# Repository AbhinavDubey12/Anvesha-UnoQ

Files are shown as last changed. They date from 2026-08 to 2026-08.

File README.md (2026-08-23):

# Anvesha — Autonomous Vision & Gesture-Controlled Rover

Autonomous rover built on the Arduino UNO Q (dual Linux MPU + STM32 MCU), combining reactive ultrasonic navigation, live on-device hand-gesture recognition via camera, and IMU-based safety monitoring — with a motor-control layer executed by a dedicated ESP32.

## Overview

By default, the rover navigates autonomously using three ultrasonic sensors (front/left/right), avoiding obstacles reactively. A physical button toggles an additional camera mode: a live ESP32-CAM feed is processed on-device by a custom-trained Edge Impulse object detection model, recognizing hand gestures that trigger specific rover actions. An MPU9250 IMU runs continuously as an independent safety layer, watching for tip-over or sudden impact regardless of what else the rover is doing. A live relay lets the camera feed be viewed from any browser on the network at the same time.

## Features

- Default autonomous reactive navigation (3x ultrasonic, North/East/West)
- Button-toggled camera mode with on-device gesture recognition (Edge Impulse FOMO, INT8, running on the UNO Q's Linux side)
- Two recognized gestures: **FULL_HAND** (controlled reverse) and **THUMPS_UP** (choreographed movement sequence)
- Live, multi-client-viewable camera feed via a custom relay
- MPU9250-based tip-over/impact safety monitoring, independent of navigation or gesture state
- LED status indicators + buzzer feedback
- UART link between the UNO Q (decision-making) and a dedicated ESP32 (motor execution)
- Per-wheel quadrature encoders for distance tracking

## Hardware Components

| Component | Role |
|---|---|
| Arduino UNO Q | Main brain — Linux (camera/AI) + STM32 (sensors/decisions) |
| ESP32 Dev Kit V1 | Motor + encoder controller |
| ESP32-CAM (AI-Thinker) | Live video source |
| 4x DC gear motors w/ quadrature encoders | Drive |
| L298N motor driver(s) | Motor power/direction |
| 3x HC-SR04 / HC-SR04P ultrasonic sensors | Reactive navigation |
| MPU9250 | IMU — safety monitoring |
| 4x LED, 1x buzzer, 1x push button | Status/mode indication |
| Chassis, wheels, battery, wiring | — |

## System Architecture

```
ESP32-CAM (video)
      ↓
UNO Q — Linux side (Python): fetch frame → Edge Impulse inference → debounce
      ↓ (Bridge RPC)
UNO Q — STM32 side (sketch): ultrasonic + IMU + LEDs/buzzer/button → decision
      ↓ (UART)
ESP32: motor execution + quadrature encoder tracking
```

## Software Stack

- **Arduino App Lab** — dual-processor (Linux + STM32) app framework
- **Python** (Linux/MPU side): OpenCV, Edge Impulse Linux SDK, a custom lightweight MJPEG relay
- **C++/Arduino** (STM32 sketch side): `Arduino_RouterBridge` for Python↔sketch RPC, ultrasonic + IMU sensing
- **C++/Arduino** (ESP32 side): UART command parsing, motor control, interrupt-driven encoder tracking

## Wiring Overview

**UNO Q**
- Ultrasonic: D2–D7 (West/North/East, trig+echo pairs)
- MPU9250: D20 (SDA) / D21 (SCL) — I2C2
- UART to ESP32: D0 (RX) / D1 (TX)
- LEDs: D8–D11 · Button: D12 · Buzzer: D13

**ESP32**
- UART: GPIO25 (RX2) / GPIO26 (TX2)
- Motor direction (shared per side): Left IN1/IN2 → GPIO27/14, Right IN1/IN2 → GPIO13/15
- Independent PWM speed: FL=32, RL=33, FR=4, RR=23
- Encoders (A/B): FL=34/35, RL=19/21, FR=2/22, RR=5/18

Full reasoning behind each pin choice is in the code comments.

## Confusion Matrix 


## Key Engineering Challenges & Solutions

- **ESP32-CAM stream reliability:** `cv2.VideoCapture`'s FFmpeg/GStreamer backend proved unreliable against the board's minimal MJPEG server under real-world network jitter. Solved with a manual `urllib` + JPEG-marker-parsing fetcher, with reconnect-on-failure logic.
- **Single-client limitation of the ESP32-CAM's server:** its onboard server can only serve one viewer at a time. Solved by having the UNO Q relay already-fetched frames to any number of viewers via a lightweight custom HTTP MJPEG relay, rather than exposing the fragile camera directly.
- **Gesture model iteration:** started from a broader gesture set; iterative testing surfaced background-labeling issues, data-volume limits, and a genuine visual-similarity ceiling between finger-count gestures. Converged on two visually distinct, reliably-separable gestures for real-world performance.
- **App Lab dependency management:** `requirements.txt` must live inside the app's `python/` subfolder (not the app root), and requires a full app close/reopen — not just a re-run — for App Lab to pick it up.
- **Platform-specific I2C differences:** the UNO Q's STM32/Zephyr core uses a fixed-pin, no-argument `Wire.begin()`, unlike the flexible-pin-argument convention common in ESP32-based reference code.
- **Motor pin budget:** adopted a shared-direction / independent-PWM wiring scheme (paired left/right direction lines, 4 independent speed lines) to fit available GPIO while preserving per-wheel encoder telemetry.

## Known Issues

- **[N] of 4 drive motors are not reliably receiving power as of submission.** Root cause narrowed via isolated diagnostic testing to a likely power-brownout-under-load condition (motor and logic power sharing a supply), with a possible additional wiring fault isolated to specific motor channels. A fix (separating ESP32 logic power from motor power) was identified but not fully re-verified before the submission deadline.
- **Full closed-loop PID speed control was intentionally deferred**, given time constraints — a simpler proportional gyro-based heading correction and raw encoder-based distance tracking were implemented instead.
- **Speech recognition was scoped but intentionally dropped** to prioritize a fully working core pipeline within the available build time.

## Demo Video

(https://drive.google.com/file/d/1g66gReOm86e0tmXK2YHVcHV1n0MQbO11/view?usp=drivesdk)

## License

[MIT]

## Author

Abhinav Dubey

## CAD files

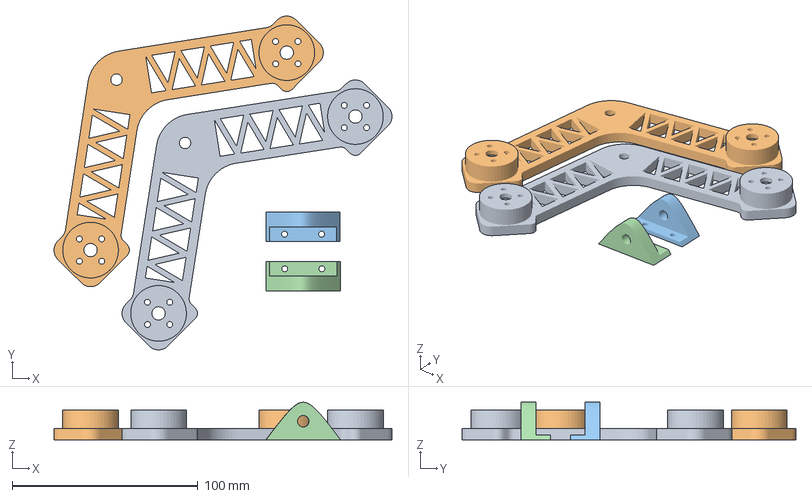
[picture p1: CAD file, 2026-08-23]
Anvesha Uno Q CAD/Right rocker.3mf
182.1 x 179.9 x 20.3 mm
Left bogie.stl
Right bogie.stl
Left_rocker mount.stl
Right_rocker mount.stl

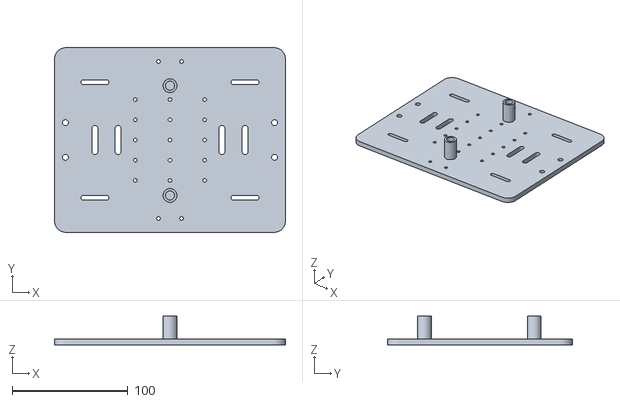
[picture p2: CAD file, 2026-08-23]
Anvesha Uno Q CAD/base_link_plate.stl
200.0 x 160.0 x 25.0

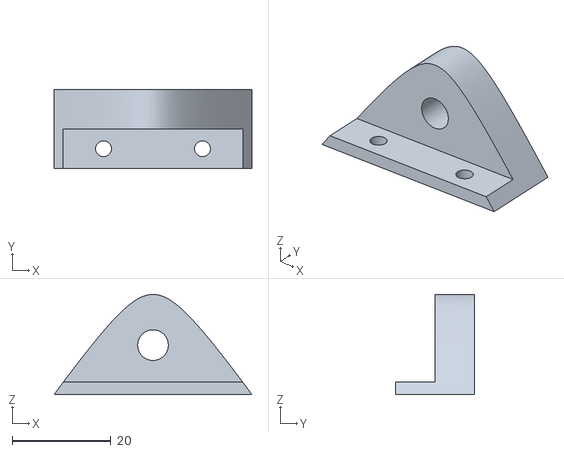
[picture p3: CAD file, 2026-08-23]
Anvesha Uno Q CAD/Left_rocker mount.stl
40.0 x 16.0 x 20.2

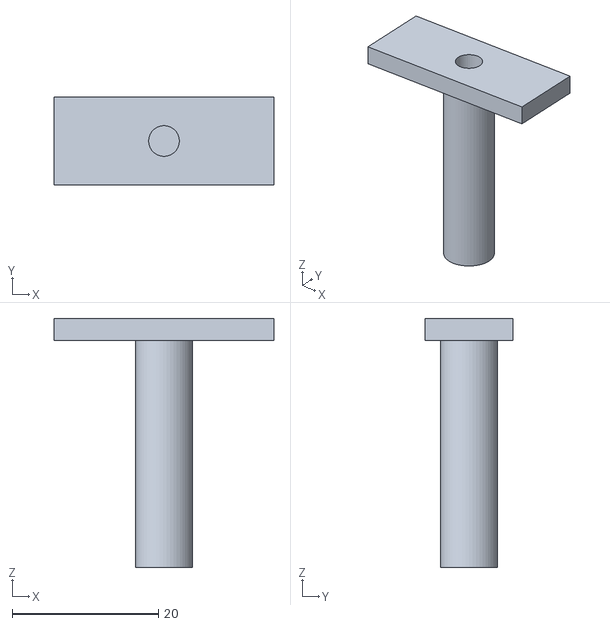
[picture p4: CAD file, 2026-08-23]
Anvesha Uno Q CAD/joint_up_base.stl
30.0 x 12.0 x 34.0

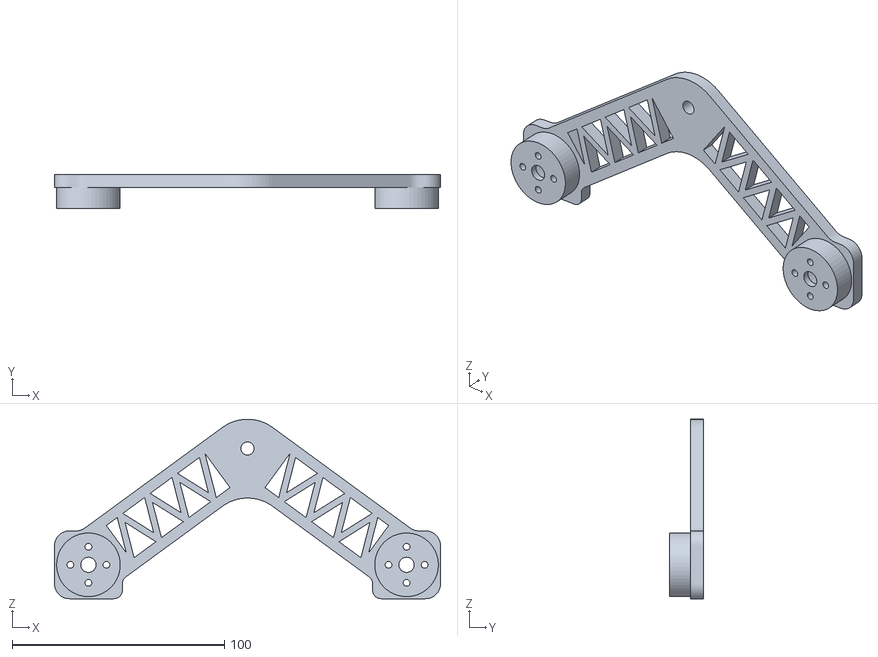
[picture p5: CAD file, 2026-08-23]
Anvesha Uno Q CAD/Right bogie.stl
182.0 x 16.0 x 84.6

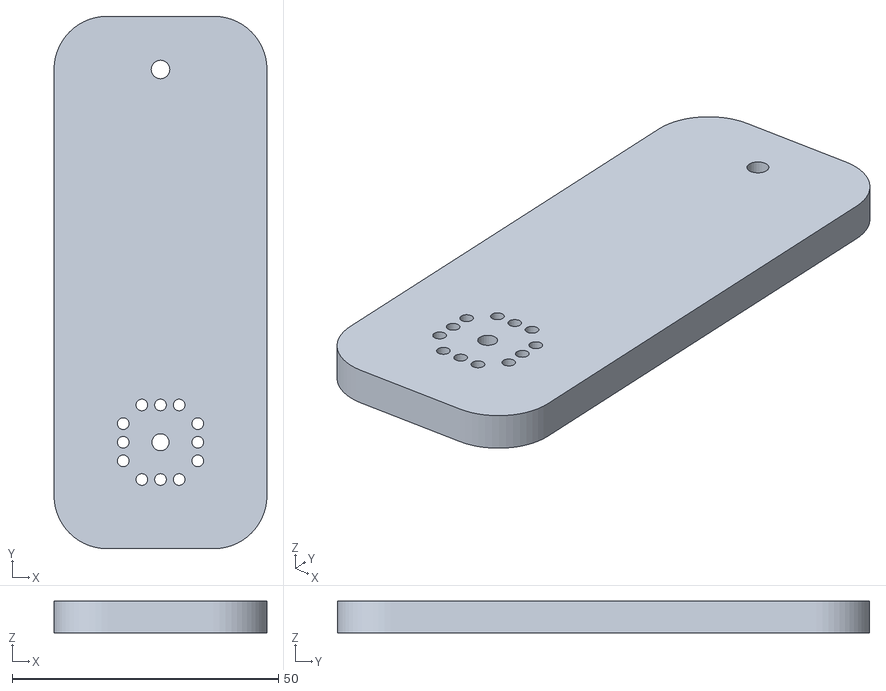
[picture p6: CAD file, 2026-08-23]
Anvesha Uno Q CAD/Servo Arm.stl
40.0 x 100.0 x 6.00

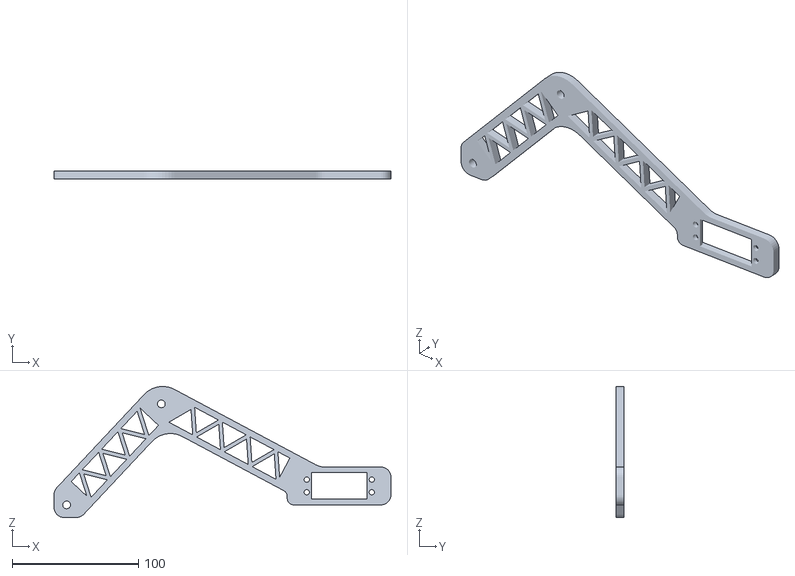
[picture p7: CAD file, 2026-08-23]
Anvesha Uno Q CAD/Left Rocker.stl
266.9 x 6.00 x 103.8

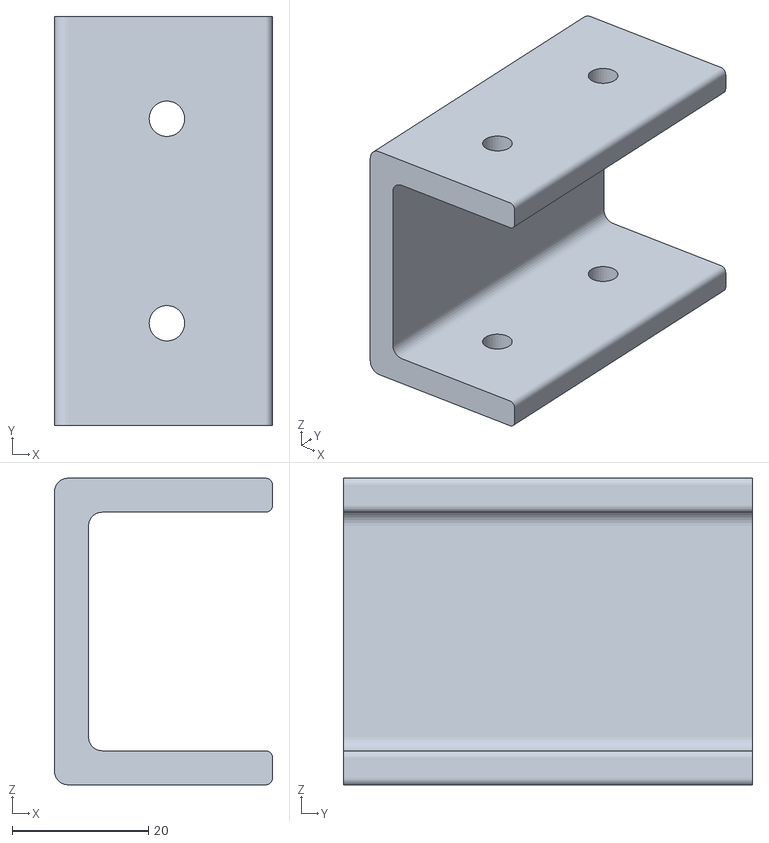
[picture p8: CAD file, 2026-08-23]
Anvesha Uno Q CAD/Connector clamp.stl
32.0 x 60.0 x 45.0

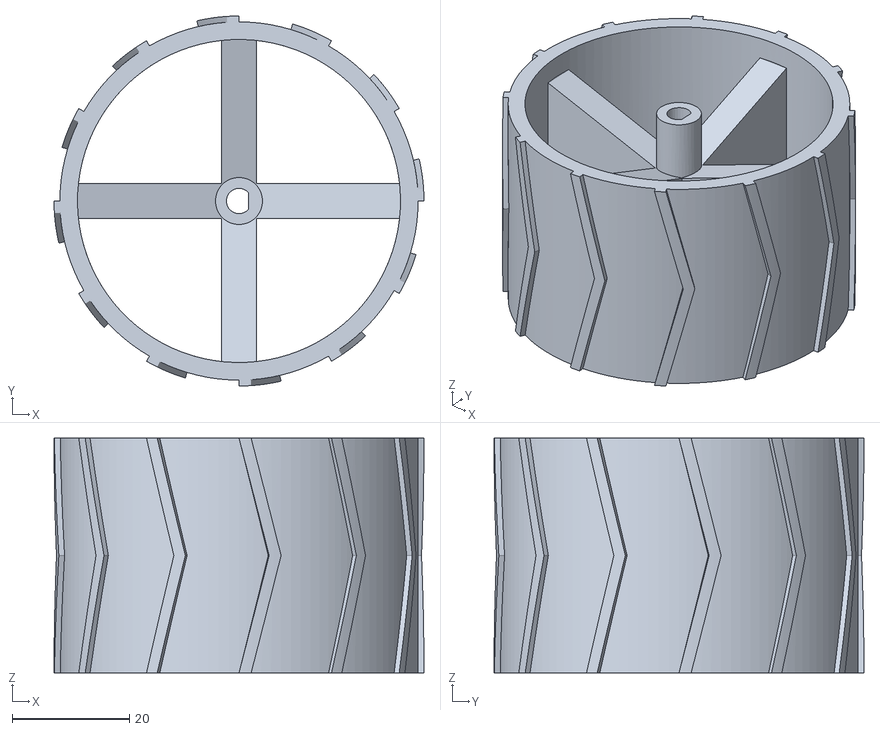
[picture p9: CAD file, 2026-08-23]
Anvesha Uno Q CAD/WheelQ.stl
63.0 x 63.0 x 40.0

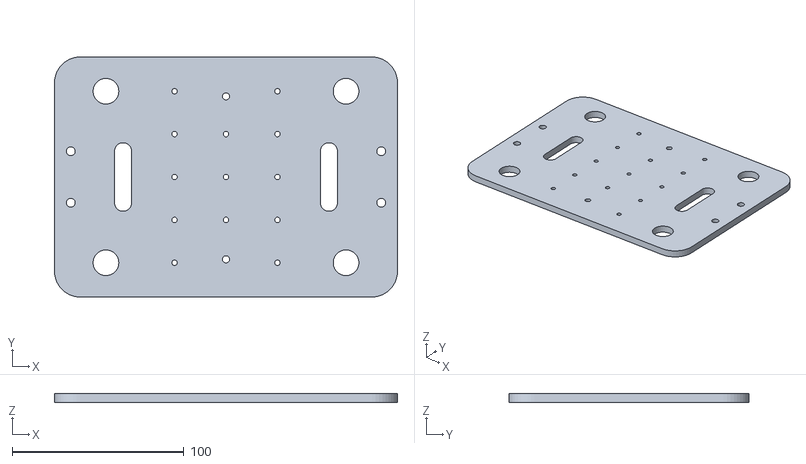
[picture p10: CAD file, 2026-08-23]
Anvesha Uno Q CAD/Upper plate.stl
200.0 x 140.0 x 5.00

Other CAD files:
Anvesha Uno Q CAD/Right_rocker mount.stl
Anvesha Uno Q CAD/Left bogie.stl
Anvesha Uno Q CAD/Right rocker.stl

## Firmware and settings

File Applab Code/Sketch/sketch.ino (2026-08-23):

#include <Arduino_RouterBridge.h>
#include <Wire.h>

// ==== Ultrasonic ====
#define TRIG_WEST 2
#define ECHO_WEST 3
#define TRIG_NORTH 4
#define ECHO_NORTH 5
#define TRIG_EAST 6
#define ECHO_EAST 7
#define BLOCKED_THRESHOLD_CM 15.0
#define DANCE_CLEARANCE_CM 25.0
#define ECHO_TIMEOUT_US 15000UL
#define SENSOR_SETTLE_MS 20
const unsigned long TX_INTERVAL_MS = 150;
unsigned long lastTxTime = 0;
unsigned long lastAckTime = 0;
#define ESP32_ACK_TIMEOUT_MS 600  // generous margin over the 150ms nav cycle
float distWest = 999, distNorth = 999, distEast = 999;

// ==== MPU9250 — tip-over/crash detection only ====
const int MPU9250_ADDRESS = 0x68;
// PLACEHOLDER thresholds — untuned, adjust after real chassis test
#define TILT_ACCEL_THRESHOLD_G 0.5   // accelZ below this while others high = likely tipped`
#define JERK_THRESHOLD_G 2.0         // sudden spike on X/Y = likely impact
float lastAccelX = 0, lastAccelY = 0, lastAccelZ = 1.0;
bool emergencyStop = false;

// ==== LEDs (D8=White, D9=Blue, D10=Green, D11=Red) ====
#define LED_WHITE 8
#define LED_BLUE 9
#define LED_GREEN 10
#define LED_RED 11

// ==== Button (D12, pull-down = active-HIGH) + Buzzer (D13) ====
#define BUTTON_PIN 12
#define BUZZER_PIN 13
bool cameraModeActive = false;
bool lastButtonReading = LOW;
unsigned long lastDebounceTime = 0;
#define DEBOUNCE_MS 50

// ==== Gesture action state ====
bool actionInProgress = false;
bool actionComplete = true; // idle default — see design note in chat
String currentAction = "";
int blockedStreak = 0;
#define STUCK_STREAK_THRESHOLD 10 // ~1.5s of continuous "blocked" at 150ms cycle

void setup() {
  Serial.begin(115200);
  Serial1.begin(9600);

  pinMode(TRIG_WEST, OUTPUT);  pinMode(ECHO_WEST, INPUT);
  pinMode(TRIG_NORTH, OUTPUT); pinMode(ECHO_NORTH, INPUT);
  pinMode(TRIG_EAST, OUTPUT);  pinMode(ECHO_EAST, INPUT);
  digitalWrite(TRIG_WEST, LOW); digitalWrite(TRIG_NORTH, LOW); digitalWrite(TRIG_EAST, LOW);

  pinMode(LED_WHITE, OUTPUT); pinMode(LED_BLUE, OUTPUT);
  pinMode(LED_GREEN, OUTPUT); pinMode(LED_RED, OUTPUT);
  pinMode(BUTTON_PIN, INPUT); // external pull-down, per your wiring
  pinMode(BUZZER_PIN, OUTPUT);

  Wire.begin();
  setupMPU9250();

  Bridge.begin();
  Bridge.provide("receive_gesture", onGestureReceived);
  Bridge.provide("is_camera_mode_active", isCameraModeActive);
  Bridge.provide("is_action_complete", isActionComplete);

  Serial.println("Anvesha_UnoQ — full system online.");
}

void loop() {
  handleButton();
  checkTipOver();

  if (millis() - lastTxTime >= TX_INTERVAL_MS) {
    lastTxTime = millis();
    distWest  = readDistanceCM(TRIG_WEST, ECHO_WEST);
    delay(SENSOR_SETTLE_MS);
    distNorth = readDistanceCM(TRIG_NORTH, ECHO_NORTH);
    delay(SENSOR_SETTLE_MS);
    distEast  = readDistanceCM(TRIG_EAST, ECHO_EAST);

    const char* navCommand = evaluateNavigation();
    updateStuckTracking(navCommand);
    updateLEDs(navCommand);

    if (!actionInProgress) {
      char payload[40];
      snprintf(payload, sizeof(payload), "<NAV:%s>", navCommand);
      Serial1.println(payload);
    }

    Serial.print("W:"); Serial.print(distWest, 1);
    Serial.print(" N:"); Serial.print(distNorth, 1);
    Serial.print(" E:"); Serial.print(distEast, 1);
    Serial.print(" nav:"); Serial.print(navCommand);
    Serial.print(" cameraMode:"); Serial.print(cameraModeActive);
    Serial.print(" ESP32:"); Serial.println((millis() - lastAckTime < ESP32_ACK_TIMEOUT_MS) ? "OK" : "NOT RESPONDING");
  }

  // Listen for ESP32 completion signal
  if (Serial1.available() > 0) {
  String msg = Serial1.readStringUntil('\n');
  msg.trim();
  if (msg == "<ACK>") {
    lastAckTime = millis();
  } else if (msg == "<DONE>" && actionInProgress) {
    actionInProgress = false;
    actionComplete = true;
    digitalWrite(BUZZER_PIN, LOW);
    Serial.println("Action complete — resuming nav.");
  }
}
}

// ==== Bridge-exposed functions ====

void onGestureReceived(String label) {
  label.trim();
  if (!cameraModeActive || actionInProgress || emergencyStop) return;

  if (label == "THUMPS_UP") {
    if (distWest < DANCE_CLEARANCE_CM || distNorth < DANCE_CLEARANCE_CM || distEast < DANCE_CLEARANCE_CM) {
      Serial.println("Dance blocked — insufficient clearance.");
      return; // stays idle, Python's poll sees actionComplete=true immediately, no hang
    }
  }

  currentAction = label;
  actionInProgress = true;
  actionComplete = false;
  digitalWrite(BUZZER_PIN, HIGH); // beep on accepting an action

  char payload[40];
  snprintf(payload, sizeof(payload), "<GESTURE:%s>", label.c_str());
  Serial1.println(payload);
  Serial.print("Gesture action started -> "); Serial.println(payload);
}

bool isCameraModeActive() { return cameraModeActive; }
bool isActionComplete() { return actionComplete; }

// ==== Button ====
void handleButton() {
  bool reading = digitalRead(BUTTON_PIN);
  if (reading != lastButtonReading) {
    lastDebounceTime = millis();
  }
  if ((millis() - lastDebounceTime) > DEBOUNCE_MS) {
    static bool stableState = LOW;
    if (reading != stableState) {
      stableState = reading;
      if (stableState == HIGH) { // press detected, active-HIGH
        cameraModeActive = !cameraModeActive;
        Serial.print("Camera mode toggled -> "); Serial.println(cameraModeActive);
      }
    }
  }
  lastButtonReading = reading;
}

// ==== Navigation ====
const char* evaluateNavigation() {
  bool frontBlocked = (distNorth <= BLOCKED_THRESHOLD_CM);
  bool leftBlocked  = (distWest  <= BLOCKED_THRESHOLD_CM);
  bool rightBlocked = (distEast  <= BLOCKED_THRESHOLD_CM);
  if (!frontBlocked) return "going forward";
  if (!leftBlocked && !rightBlocked) return (distWest >= distEast) ? "move left" : "move right";
  if (!leftBlocked) return "move left";
  if (!rightBlocked) return "move right";
  return "blocked";
}

void updateStuckTracking(const char* navCommand) {
  if (strcmp(navCommand, "blocked") == 0) blockedStreak++;
  else blockedStreak = 0;
  if (blockedStreak == STUCK_STREAK_THRESHOLD) {
    digitalWrite(BUZZER_PIN, HIGH);
    delay(150);
    digitalWrite(BUZZER_PIN, LOW);
  }
}

void updateLEDs(const char* navCommand) {
  digitalWrite(LED_WHITE, (actionInProgress && currentAction == "FULL_HAND"));
  digitalWrite(LED_BLUE,  (actionInProgress && currentAction == "THUMPS_UP"));
  digitalWrite(LED_RED,   (!actionInProgress && strcmp(navCommand, "blocked") == 0));
  digitalWrite(LED_GREEN, (!actionInProgress && strcmp(navCommand, "blocked") != 0));
}

float readDistanceCM(int trigPin, int echoPin) {
  if (digitalRead(echoPin) == HIGH) return 999.0;
  digitalWrite(trigPin, LOW); delayMicroseconds(2);
  digitalWrite(trigPin, HIGH); delayMicroseconds(10);
  digitalWrite(trigPin, LOW);
  unsigned long duration = pulseIn(echoPin, HIGH, ECHO_TIMEOUT_US);
  return (duration == 0) ? 999.0 : duration / 58.0;
}

// ==== MPU9250 ====
void setupMPU9250() {
  writeMPU9250(MPU9250_ADDRESS, 0x6B, 0x00);
  writeMPU9250(MPU9250_ADDRESS, 0x1B, 0x00);
  writeMPU9250(MPU9250_ADDRESS, 0x1C, 0x00);
}
void writeMPU9250(byte address, byte reg, byte data) {
  Wire.beginTransmission(address); Wire.write(reg); Wire.write(data); Wire.endTransmission();
}
void checkTipOver() {
  Wire.beginTransmission(MPU9250_ADDRESS);
  Wire.write(0x3B);
  Wire.endTransmission(false);
  Wire.requestFrom(MPU9250_ADDRESS, 6, true);
  if (Wire.available() < 6) return;
  int16_t rawX = (Wire.read() << 8) | Wire.read();
  int16_t rawY = (Wire.read() << 8) | Wire.read();
  int16_t rawZ = (Wire.read() << 8) | Wire.read();
  float ax = rawX / 16384.0, ay = rawY / 16384.0, az = rawZ / 16384.0;

  bool tilted = (abs(az) < TILT_ACCEL_THRESHOLD_G);
  bool jerked = (abs(ax - lastAccelX) > JERK_THRESHOLD_G) || (abs(ay - lastAccelY) > JERK_THRESHOLD_G);
  emergencyStop = tilted || jerked;
  if (emergencyStop) {
    Serial1.println("<EMERGENCY:stop>");
    digitalWrite(LED_RED, HIGH);
  }
  lastAccelX = ax; lastAccelY = ay; lastAccelZ = az;
}

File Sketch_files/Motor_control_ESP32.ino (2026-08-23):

#include <Arduino.h>

#define RXD2 25
#define TXD2 26

#define LEFT_IN1 27
#define LEFT_IN2 14
#define RIGHT_IN1 13
#define RIGHT_IN2 15
#define FL_EN 32
#define RL_EN 33
#define FR_EN 4
#define RR_EN 23

#define FL_ENCA 34
#define FL_ENCB 35
#define RL_ENCA 19
#define RL_ENCB 21
#define FR_ENCA 2
#define FR_ENCB 22
#define RR_ENCA 5
#define RR_ENCB 18

volatile long posFL = 0, posRL = 0, posFR = 0, posRR = 0;
const int DRIVE_PWM = 110;

// PPR=117, wheel circumference 20.4cm -> ticks for 20cm = (20/20.4)*117 ≈ 115
#define REVERSE_TARGET_TICKS 115
#define DANCE_BEAT_MS 1000
#define DANCE_GAP_MS 100

unsigned long lastPacketTime = 0;
const unsigned long TIMEOUT_LIMIT_MS = 1000;
bool busy = false;

void IRAM_ATTR readEncoderFL();
void IRAM_ATTR readEncoderRL();
void IRAM_ATTR readEncoderFR();
void IRAM_ATTR readEncoderRR();

void setup() {
  Serial.begin(115200);
  Serial2.begin(9600, SERIAL_8N1, RXD2, TXD2);

  pinMode(LEFT_IN1, OUTPUT); pinMode(LEFT_IN2, OUTPUT);
  pinMode(RIGHT_IN1, OUTPUT); pinMode(RIGHT_IN2, OUTPUT);
  pinMode(FL_EN, OUTPUT); pinMode(RL_EN, OUTPUT);
  pinMode(FR_EN, OUTPUT); pinMode(RR_EN, OUTPUT);

  pinMode(FL_ENCA, INPUT); pinMode(FL_ENCB, INPUT);
  pinMode(FR_ENCA, INPUT); pinMode(FR_ENCB, INPUT);
  pinMode(RL_ENCA, INPUT_PULLUP); pinMode(RL_ENCB, INPUT_PULLUP);
  pinMode(RR_ENCA, INPUT_PULLUP); pinMode(RR_ENCB, INPUT_PULLUP);

  attachInterrupt(digitalPinToInterrupt(FL_ENCA), readEncoderFL, RISING);
  attachInterrupt(digitalPinToInterrupt(RL_ENCA), readEncoderRL, RISING);
  attachInterrupt(digitalPinToInterrupt(FR_ENCA), readEncoderFR, RISING);
  attachInterrupt(digitalPinToInterrupt(RR_ENCA), readEncoderRR, RISING);

  stopAll();
  lastPacketTime = millis();
  Serial.println("ESP32 Motor Node — full system ready.");
}

void loop() {
  readUARTStream();
  if (!busy && (millis() - lastPacketTime > TIMEOUT_LIMIT_MS)) {
    stopAll();
  }
}

void readUARTStream() {
  static boolean recvInProgress = false;
  static char rxBuffer[40];
  static byte idx = 0;

  while (Serial2.available() > 0) {
    char rc = Serial2.read();
    if (recvInProgress) {
      if (rc != '>') {
        if (idx < sizeof(rxBuffer) - 1) rxBuffer[idx++] = rc;
      } else {
        rxBuffer[idx] = '\0';
        recvInProgress = false;
        idx = 0;
        lastPacketTime = millis();
        routePacket(rxBuffer);
      }
    } else if (rc == '<') {
      recvInProgress = true;
      idx = 0;
    }
  }
}

void routePacket(char* packet) {
  if (strncmp(packet, "EMERGENCY:", 10) == 0) {
    stopAll();
    busy = false;
    Serial.println("EMERGENCY STOP received.");
    return;
  }
  if (strncmp(packet, "NAV:", 4) == 0) {
    if (busy) return; // ignore nav while executing a gesture action
    executeNav(packet + 4);
    return;
  }
  if (strncmp(packet, "GESTURE:", 8) == 0) {
    if (busy) return;
    executeGesture(packet + 8);
    return;
  }
}

void executeNav(char* cmd) {
  if (strcmp(cmd, "going forward") == 0) driveMotors(1, 1, DRIVE_PWM);
  else if (strcmp(cmd, "move left") == 0) driveMotors(-1, 1, DRIVE_PWM);
  else if (strcmp(cmd, "move right") == 0) driveMotors(1, -1, DRIVE_PWM);
  else if (strcmp(cmd, "blocked") == 0) stopAll();
}

void executeGesture(char* label) {
  busy = true;
  if (strcmp(label, "FULL_HAND") == 0) {
    doReverse20cm();
  } else if (strcmp(label, "THUMPS_UP") == 0) {
    doDance();
  }
  stopAll();
  busy = false;
  Serial2.println("<DONE>");
}

void doReverse20cm() {
  posFL = posRL = posFR = posRR = 0;
  driveMotors(-1, -1, DRIVE_PWM);
  while (true) {
    long avgTicks = (abs(posFL) + abs(posRL) + abs(posFR) + abs(posRR)) / 4;
    if (avgTicks >= REVERSE_TARGET_TICKS) break;
    lastPacketTime = millis(); // feed watchdog while legitimately busy
    delay(10);
  }
}

void doDance() {
  // F-R-L-B-F-R-L, 1s per beat, 100ms gap
  int leftDirs[]  = { 1, -1,  1, -1,  1, -1,  1};
  int rightDirs[] = { 1,  1, -1, -1,  1,  1, -1};
  for (int i = 0; i < 7; i++) {
    driveMotors(leftDirs[i], rightDirs[i], DRIVE_PWM);
    unsigned long start = millis();
    while (millis() - start < DANCE_BEAT_MS) {
      lastPacketTime = millis();
      delay(10);
    }
    stopAll();
    delay(DANCE_GAP_MS);
  }
}

void driveMotors(int leftDir, int rightDir, int pwmSpeed) {
  setDirection(LEFT_IN1, LEFT_IN2, leftDir);
  setDirection(RIGHT_IN1, RIGHT_IN2, rightDir);
  analogWrite(FL_EN, pwmSpeed); analogWrite(RL_EN, pwmSpeed);
  analogWrite(FR_EN, pwmSpeed); analogWrite(RR_EN, pwmSpeed);
}

void stopAll() {
  setDirection(LEFT_IN1, LEFT_IN2, 0);
  setDirection(RIGHT_IN1, RIGHT_IN2, 0);
  analogWrite(FL_EN, 0); analogWrite(RL_EN, 0);
  analogWrite(FR_EN, 0); analogWrite(RR_EN, 0);
}

void setDirection(int in1, int in2, int dir) {
  if (dir == 1) { digitalWrite(in1, HIGH); digitalWrite(in2, LOW); }
  else if (dir == -1) { digitalWrite(in1, LOW); digitalWrite(in2, HIGH); }
  else { digitalWrite(in1, LOW); digitalWrite(in2, LOW); }
}

void IRAM_ATTR readEncoderFL() { posFL += (digitalRead(FL_ENCB) == HIGH) ? 1 : -1; }
void IRAM_ATTR readEncoderRL() { posRL += (digitalRead(RL_ENCB) == HIGH) ? 1 : -1; }
void IRAM_ATTR readEncoderFR() { posFR += (digitalRead(FR_ENCB) == HIGH) ? 1 : -1; }
void IRAM_ATTR readEncoderRR() { posRR += (digitalRead(RR_ENCB) == HIGH) ? 1 : -1; }
